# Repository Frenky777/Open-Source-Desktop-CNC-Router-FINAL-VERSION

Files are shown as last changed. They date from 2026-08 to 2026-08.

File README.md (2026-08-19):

#Description
Welcome to my Open Source Desktop CNC Router project! 

This is a fully functional, DIY 3-axis CNC machine designed for  wood, acrylic, PCBs, light aluminum. It is built around affordable and accessible components, making it a perfect project for makers and hobbyists.

Key Features:

Controller: MKS DLC32 v2.1 running GRBL/FluidNC for reliable wireless and offline control.
Power: Robust 24V system powered by a 200W Mean Well Power Supply.
Motors: Standard NEMA 17 stepper motors ] for precise movements.
Open Source: Files are provided for the community to build, modify, and improve!
Please read the Bill of Materials (BOM) carefully before starting your build.

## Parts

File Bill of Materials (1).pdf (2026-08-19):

/ Bill of Materials (BOM) Electronics (Elektronika)

- 1x MKS DLC32 v2.1 Motherboard
- 1x Mean Well 24V 200W Power Supply (e.g., LRS-200-24)
- 3x TMC2209 Stepper Motor Drivers
- 3x NEMA 17 Stepper Motors (70mm/48mm body length / high torque) depends how fast and cheap you want to build it
- 1x NEMA 17 Stepper Motor (38mm just be fine)
- 1x AC Power Socket (IEC C14 with switch)
- 3m AC Power Cable (2x1.5mm²)
- 4x Stepper Motor Extension Cables
- 3x Micro Limit Switches / Endstops
- 3x Endstop Cables (2-pin/3-pin)

Motion & Mechanics (Mechanika i Napęd)

- 3x T8x8 Trapezoidal Lead Screws - 500mm length (X/Y axes)
- 1x T8x8 Trapezoidal Lead Screw - 200mm length (Z axis)
- 6x 12mm Linear Smooth Rods/Guides – 500/550mm length (500 be fine but you can use 550)
- 2x 8mm Linear Smooth Rods/Guides - 500mm length
- 2x 8mm Linear Smooth Rods/Guides - 150mm length
- 3x Flexible Shaft Couplers (5mm to 8mm)
- 1x 10/16T GT2 Pulley (5mm bore)
- 1x 20T GT2 Pulley (8mm bore)
- 1x GT2 Closed Loop Timing Belt - 200mm length
- 4x LM12LUU (Long) Linear Bearings
- 4x LM12UU (Short) Linear Bearings
- 8x LM8UU Linear Bearings
- 5x 608ZZ Ball Bearings (8x22x7mm)
- 2x 8mm Shaft Lock Collars / Rings

Frame & Hardware (Konstrukcja)

- 7x 2020 Aluminum Extrusions - 500mm length
- 10x 2020 3-way Corner Brackets (Cube brackets)
- 1x MDF Spoilboard (400x600mm, 18mm thickness)

- Lot x M3 Threaded Heat Set Inserts (OD 4.2mm)
- Lot x Assorted M4/M5 Screws and T-Nuts for 2020 extrusions

Spindle (Wrzeciono)

- 1x Makita 3709 Router (or any other 65mm diameter spindle/trim router)
- I used In Newest Version Parkside Performance PPMF 710 A1 Because it`s cheap and it has a spindle speed control

3D Printing Recommendations (Zalecenia druku)

- It takes about 2kg of filament
- Material: PETG, ABS, ASA, or PLA-CF (Do NOT use standard PLA due to stepper motor heat).
- Walls/Perimeters: 4 Wall Loops (minimum) for strength.
- Infill: 20-40% Gyroid or Cubic. (I used Gyroid)

•
You can use basically any 3D printer for this project — just be patient, because it takes a lot of filament and a good amount of time. I printed the parts on a Bambu Lab A1, Bambu Lab X1C, Bambu Lab H2S, and a Creality K1 Max.

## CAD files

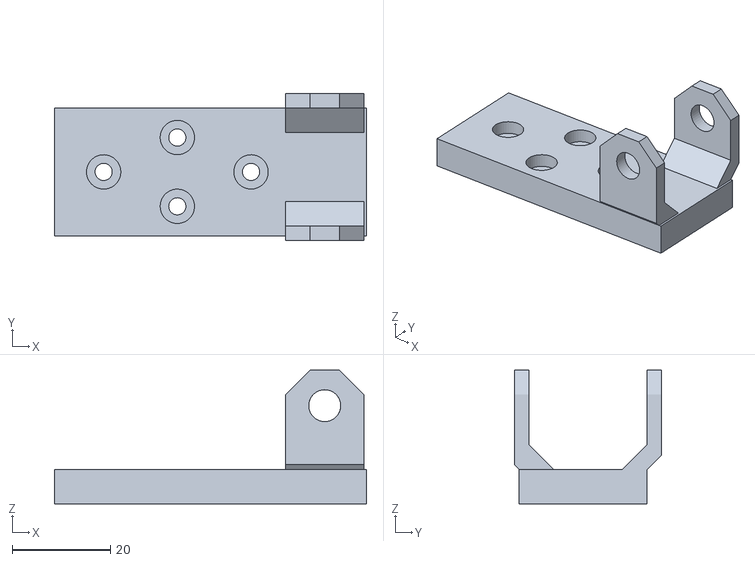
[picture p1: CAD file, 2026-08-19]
3d files/CNC HEAD AND Z AXIS/cnc head cable chain.stl
63.5 x 30.0 x 27.2

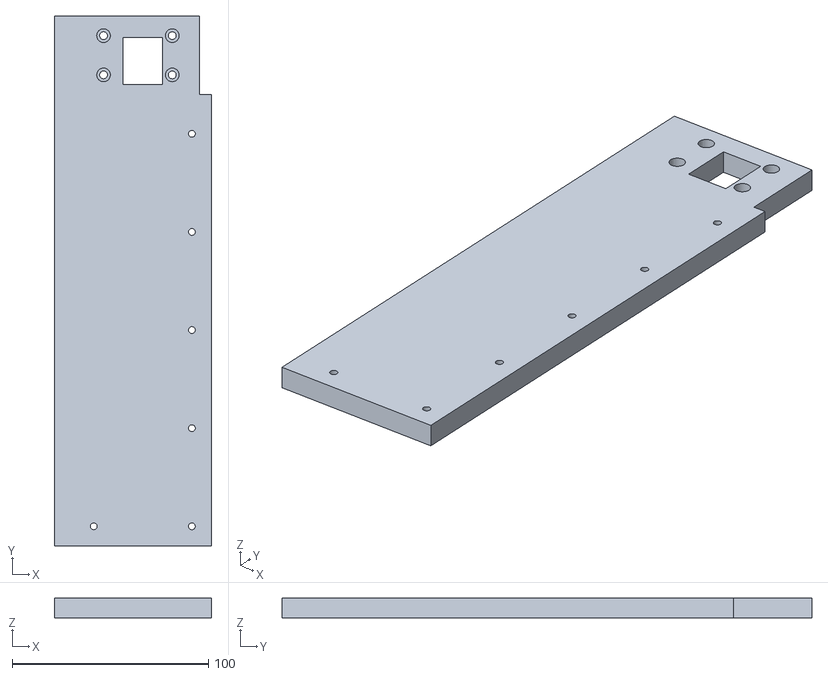
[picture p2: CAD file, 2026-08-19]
3d files/COVERS FROM DUST (print 1 each)/right engine cover lol.stl
80.0 x 270.0 x 10.0

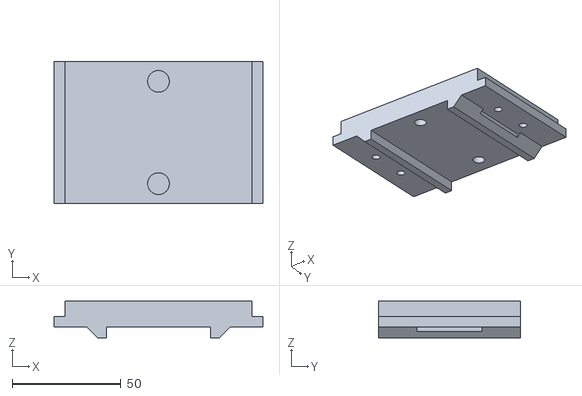
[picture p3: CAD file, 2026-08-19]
3d files/ELECTRONICS CASES/for ac spindle control.stl
96.0 x 65.0 x 16.8

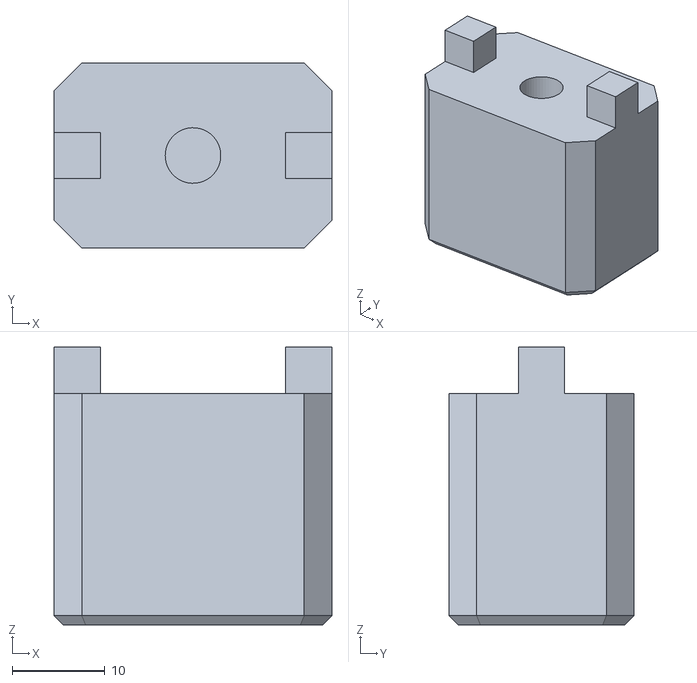
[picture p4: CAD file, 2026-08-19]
3d files/SpoilBoard and LEGS mount/single leg.stl
30.0 x 20.0 x 30.0

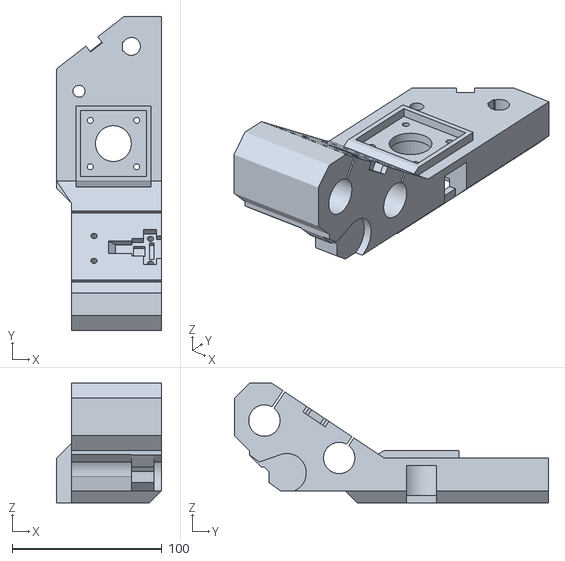
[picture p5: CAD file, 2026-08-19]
3d files/X AXIS/right side head mounting.stl
70.0 x 210.0 x 80.0

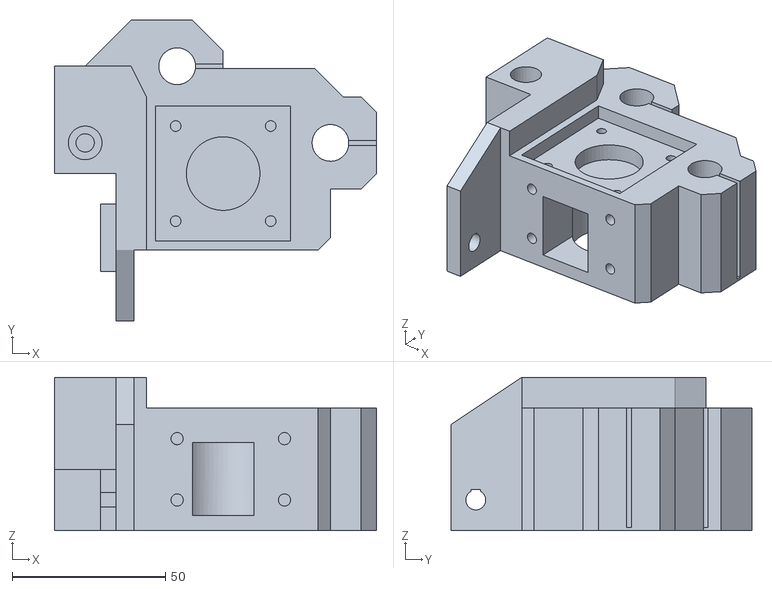
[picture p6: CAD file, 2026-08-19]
3d files/Y AXIS/left side engine mount.stl
105.0 x 98.0 x 50.0

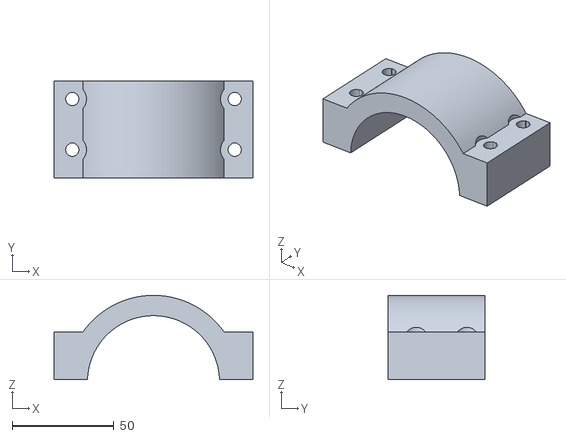
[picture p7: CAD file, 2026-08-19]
3d files/CNC HEAD AND Z AXIS/spindle second half mount.stl
98.0 x 48.0 x 41.5

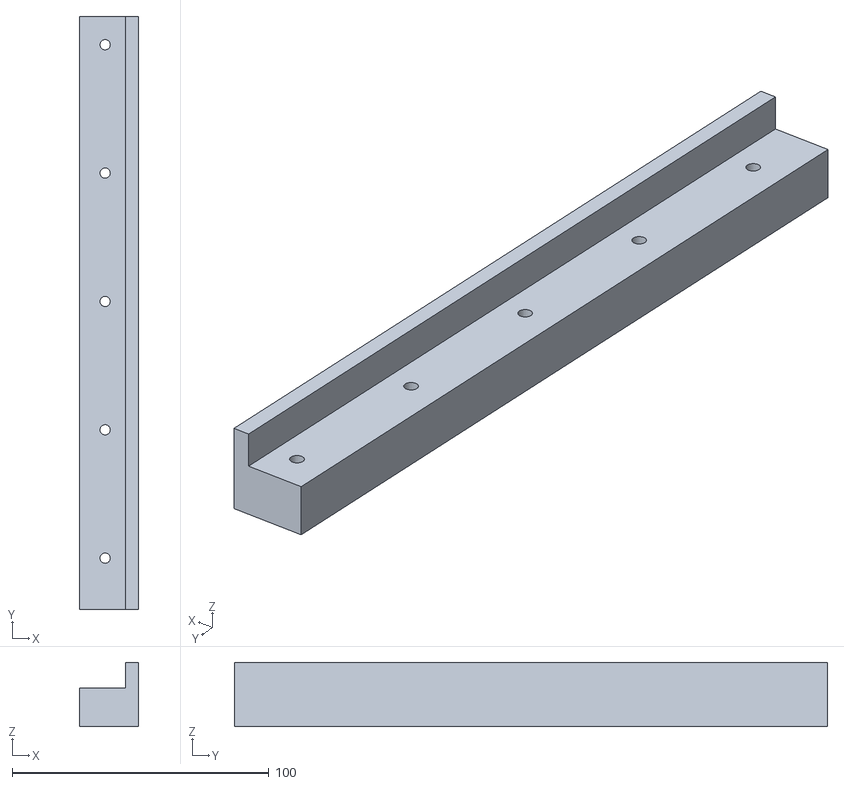
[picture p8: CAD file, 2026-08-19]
3d files/COVERS FROM DUST (print 1 each)/right engine cover part 2.stl
23.0 x 231.0 x 25.0

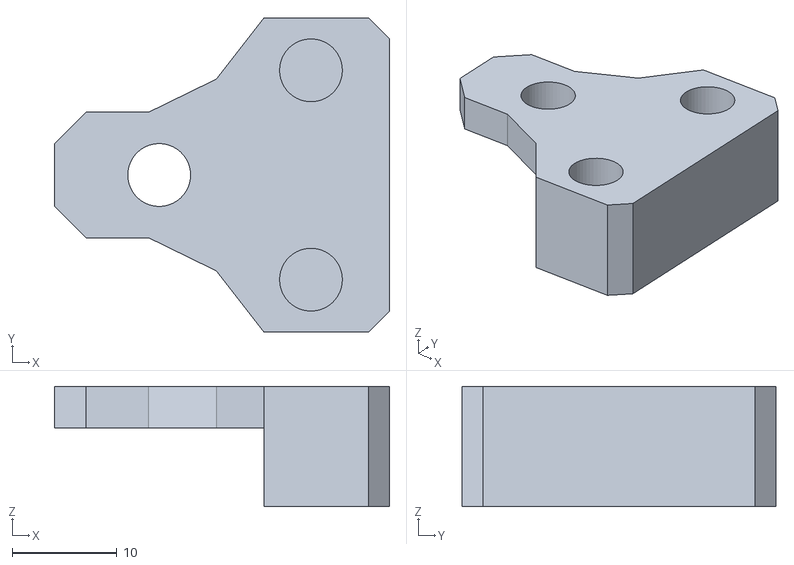
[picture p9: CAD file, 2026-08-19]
3d files/ELECTRONICS CASES/psu mount and spindle controller mount print 4x.stl
32.0 x 30.0 x 11.5

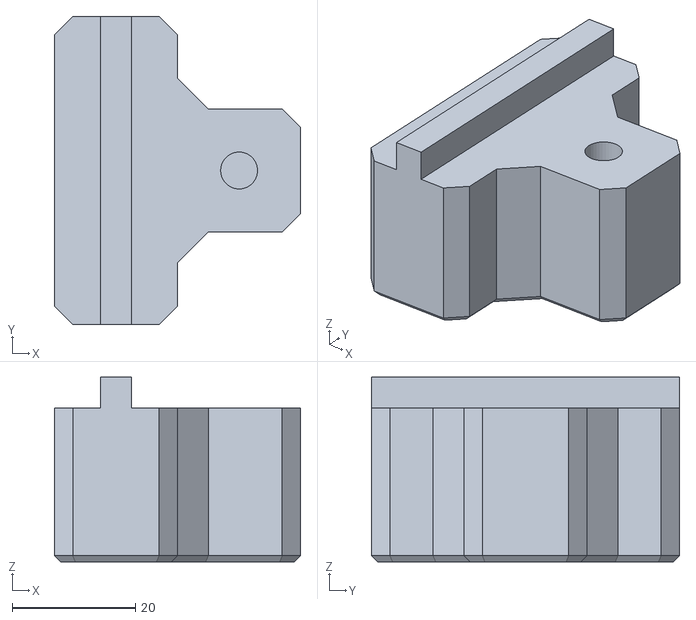
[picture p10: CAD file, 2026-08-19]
3d files/SpoilBoard and LEGS mount/tripple leg.stl
40.0 x 50.0 x 30.0

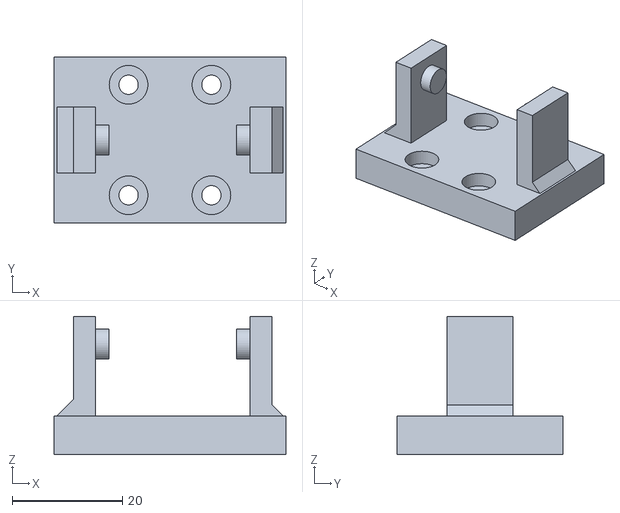
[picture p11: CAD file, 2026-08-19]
3d files/X AXIS/chain mount 1.stl
42.0 x 30.0 x 25.0

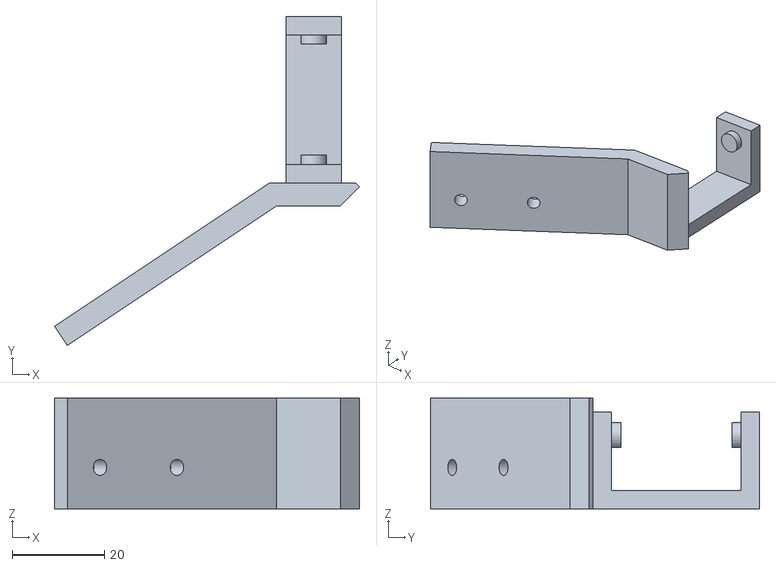
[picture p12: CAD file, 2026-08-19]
3d files/Y AXIS/y chain mount.stl
66.0 x 71.2 x 24.0

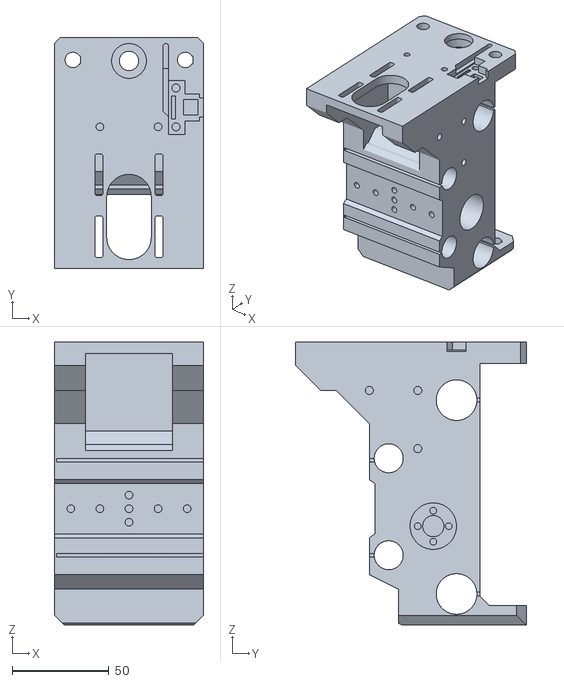
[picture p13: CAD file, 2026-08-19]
3d files/CNC HEAD AND Z AXIS/cnc head.stl
77.0 x 119.0 x 146.0

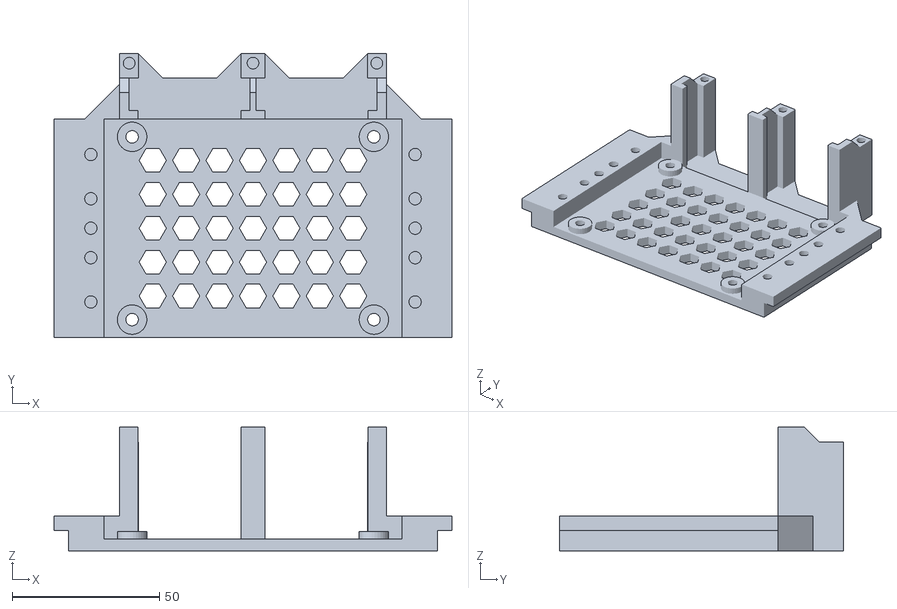
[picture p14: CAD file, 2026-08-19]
3d files/ELECTRONICS CASES/mks dlc 32 v2.1 mount.stl
135.0 x 96.2 x 42.0

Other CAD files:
3d files/COVERS FROM DUST (print 1 each)/left engine cover lol.stl
3d files/SpoilBoard and LEGS mount/left corner leg.stl
3d files/X AXIS/left side head mounting.stl
3d files/Y AXIS/rolls mount right.stl
3d files/CNC HEAD AND Z AXIS/cnc head cable chain.f3d
3d files/CNC HEAD AND Z AXIS/cnc head.f3d
3d files/CNC HEAD AND Z AXIS/head mount.f3d
3d files/CNC HEAD AND Z AXIS/head mount.stl
3d files/CNC HEAD AND Z AXIS/spindle second half mount.f3d
3d files/CNC HEAD AND Z AXIS/szczota kurwa.f3d
3d files/CNC HEAD AND Z AXIS/szczota kurwa.stl
3d files/COVERS FROM DUST (print 1 each)/cover rolls mount left part 2.f3d
3d files/COVERS FROM DUST (print 1 each)/cover rolls mount left part 2.stl
3d files/COVERS FROM DUST (print 1 each)/cover rolls mount left.f3d
3d files/COVERS FROM DUST (print 1 each)/cover rolls mount left.stl
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

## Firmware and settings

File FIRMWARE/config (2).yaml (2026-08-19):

board: MKS-DLC32 V2.1
name: K40 FLAKOV CNC
meta: (19.05.2026) by Frenkie
kinematics: {}
stepping:
  engine: I2S_STATIC
  idle_ms: 255
  pulse_us: 4
  dir_delay_us: 1
  disable_delay_us: 0
axes:
  shared_stepper_disable_pin: i2so.0
  x:
    steps_per_mm: 800
    max_rate_mm_per_min: 1200
    acceleration_mm_per_sec2: 50
    max_travel_mm: 350
    soft_limits: true
    homing:
      cycle: 1
      positive_direction: false
      mpos_mm: 0
      feed_mm_per_min: 100
      seek_mm_per_min: 500
      settle_ms: 500
      seek_scaler: 1.1
      feed_scaler: 1.1
    motor0:
      limit_neg_pin: gpio.36
      hard_limits: false
      pulloff_mm: 2
      stepstick:
        step_pin: I2SO.1
        direction_pin: I2SO.2
      limit_pos_pin: NO_PIN
      limit_all_pin: NO_PIN
  y:
    steps_per_mm: 400
    max_rate_mm_per_min: 1200
    acceleration_mm_per_sec2: 50
    max_travel_mm: 370
    soft_limits: true
    homing:
      cycle: 1
      positive_direction: false
      mpos_mm: 0
      feed_mm_per_min: 100
      seek_mm_per_min: 500
      settle_ms: 500
      seek_scaler: 1.1
      feed_scaler: 1.1
    motor0:
      limit_neg_pin: gpio.35
      hard_limits: false
      pulloff_mm: 2
      stepstick:
        step_pin: I2SO.5
        direction_pin: I2SO.6
      limit_pos_pin: NO_PIN
      limit_all_pin: NO_PIN
  z:
    steps_per_mm: 400
    max_rate_mm_per_min: 300
    acceleration_mm_per_sec2: 25
    max_travel_mm: 52
    soft_limits: true
    homing:
      cycle: 0
      positive_direction: true
      mpos_mm: 0
      feed_mm_per_min: 100
      seek_mm_per_min: 500
      settle_ms: 500
      seek_scaler: 1.1
      feed_scaler: 1.1
    motor0:
      limit_neg_pin: NO_PIN
      hard_limits: false
      pulloff_mm: 1
      stepstick:
        step_pin: I2SO.3
        direction_pin: I2SO.4
      limit_pos_pin: gpio.34
      limit_all_pin: NO_PIN
i2so:
  bck_pin: gpio.16
  data_pin: gpio.21
  ws_pin: gpio.17
spi:
  miso_pin: gpio.12
  mosi_pin: gpio.13
  sck_pin: gpio.14
sdcard:
  cs_pin: gpio.15
  card_detect_pin: NO_PIN
control:
  safety_door_pin: NO_PIN
  reset_pin: NO_PIN
  feed_hold_pin: NO_PIN
  cycle_start_pin: NO_PIN
  macro0_pin: gpio.33:low:pu
  macro1_pin: NO_PIN
  macro2_pin: NO_PIN
  macro3_pin: NO_PIN
macros:
  macro0: $SD/Run=lasertest.gcode
  macro1: $SD/Run=home.gcode
coolant:
  flood_pin: NO_PIN
  mist_pin: NO_PIN
  delay_ms: 0
probe:
  pin: gpio.22
  check_mode_start: true
Laser:
  pwm_hz: 5000
  output_pin: gpio.32
  enable_pin: i2so.7
  disable_with_s0: false
  s0_with_disable: false
  tool_num: 0
  speed_map: 0=0.000% 0=12.500% 1700=100.000%
user_outputs:
  analog0_pin: NO_PIN
  analog1_pin: NO_PIN
  analog2_pin: NO_PIN
  analog3_pin: NO_PIN
  analog0_hz: 5000
  analog1_hz: 5000
  analog2_hz: 5000
  analog3_hz: 5000
  digital0_pin: NO_PIN
  digital1_pin: NO_PIN
  digital2_pin: NO_PIN
  digital3_pin: NO_PIN
start:
  must_home: false
